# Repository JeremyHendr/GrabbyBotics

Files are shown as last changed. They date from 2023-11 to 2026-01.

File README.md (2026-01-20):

# Grabby – Modular Autonomous Mobile Robot for Warehouse Research  
**Authors:** Jeremy Hendrikse, Julius Ortstadt  

## Introduction
This repository contains all software, hardware designs, and documentation related to **Grabby**, an autonomous mobile robot developed as a **proof of concept for warehouse automation and indoor autonomous navigation research**.

The project has been developed over a three-year period as part of the Master’s program in *Robotics and Autonomous Systems* at **Polytech Nice-Sophia**. The primary objective is not direct industrial deployment, but rather the exploration, integration, and evaluation of autonomous navigation techniques on a self-designed robotic platform.

The system is intentionally modular and extensible, serving as a research and experimentation base for mapping, localization, navigation, and manipulation in structured indoor environments.

> The robot architecture is divided into two main subsystems:
> - **Mobile Base**  
>   Responsible for locomotion, power distribution, onboard computation, and autonomous navigation. It hosts the main computer, battery system, sensors, and motor controllers.
> - **Lifting Platform**  
>   A modular upper subsystem designed for package handling. It includes lifting and grabbing mechanisms as well as additional sensors, such as a stereo camera, to assist with perception and task execution.

---

## Software
This section contains all software developed for the robot, covering low-level control, autonomy, and system integration.

The mobile base software stack is built around **ROS 1 (Melodic)** and includes:
- Teleoperation (wireless controller)
- SLAM and mapping
- Localization (AMCL)
- Autonomous navigation
- Sensor fusion (LiDAR and IMU)
- Motor control and odometry

Due to the use of **Ubuntu 24.04 LTS on ARM64**, ROS 1 is executed inside a **Docker container**, ensuring compatibility and reproducibility despite ROS 1 being end-of-life. Detailed configuration steps are provided in the documentation.

The repository also includes:
- Code for Arduino Nano boards
- Parameter tuning files
- Auxiliary scripts and configuration tools

---

## Hardware
The hardware section contains all design files required to reproduce the robot.

Included are:
- 3D models (Fusion 360)
- 2D designs and schematics (Inkscape)
- Mechanical adapters and modular interfaces

The robot features a **modular chassis built from 20×20 mm aluminum profiles**, carbon-reinforced 3D-printed components, and a decentralized electronics architecture. All subsystems are designed for easy assembly, disassembly, and replacement.

---

## Documentation
This section provides comprehensive documentation covering both hardware and software aspects of the project.

It includes:
- Detailed setup instructions for **Ubuntu Server 24.04 LTS** on Raspberry Pi 5
- ROS 1 Melodic installation and configuration using Docker on ARM64
- Mapping and navigation workspace setup
- Sensor configuration and calibration
- Power system design and safety considerations
- Troubleshooting guides and known limitations

All source code, CAD files, and supporting materials are available in this repository to facilitate reproducibility and further development.

---

## Acknowledgements
The development of this project was made possible through the support of **Polytech Nice-Sophia**, which provided the necessary funding, equipment, and academic framework.  
Special thanks are extended to the professors for their guidance in robotics, electronics, sensor fusion, and autonomous systems, which formed the foundation of this work.

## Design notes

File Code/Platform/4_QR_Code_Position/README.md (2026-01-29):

# QR Code 3D Position Detection using Stereo Vision

This project detects QR codes in a stereo camera setup and calculates their 3D position in space using triangulation.

## Coordinate System and Camera Setup

### Origin and Coordinate Frame

The **origin of the coordinate system is at the LEFT camera's optical center**.

**Coordinate axes:**
- **X-axis**: Points to the right (horizontal, positive = right side)
- **Y-axis**: Points downward (vertical, positive = down)  
- **Z-axis**: Points forward into the scene (depth, positive = away from camera)

```
        Y (down)
        |
        |
        |______ X (right)
       /
      /
     Z (forward)
```

### Stereo Camera Configuration

The stereo setup consists of two cameras arranged horizontally:

- **Left Camera**: Reference camera (origin of coordinate system)
- **Right Camera**: Positioned to the right of the left camera

**Baseline**: The distance between the two camera centers (typically 60-120 mm)

### Extrinsic Parameters

The relationship between the two cameras is described by extrinsic parameters:

#### Rotation Matrix (R)
A 3×3 matrix describing the rotation from the left camera frame to the right camera frame. For a parallel stereo setup (rectified cameras), this is typically close to the identity matrix.

```
R = [[r11  r12  r13]
     [r21  r22  r23]
     [r31  r32  r33]]
```

#### Translation Vector (T)
A 3×1 vector describing the translation from the left camera center to the right camera center.

```
T = [[Tx]    (horizontal displacement - baseline)
     [Ty]    (vertical displacement - ideally 0)
     [Tz]]   (depth displacement - ideally 0)
```

For an ideal horizontal stereo setup:
- `Tx = -baseline` (negative because right camera is to the left's right)
- `Ty ≈ 0` (cameras at same height)
- `Tz ≈ 0` (cameras at same depth)

**Note**: The baseline used in triangulation is `baseline = |Tx|` (absolute value of the x-component of the translation vector).

### Intrinsic Parameters

Each camera has its own intrinsic parameters stored in the camera matrix:

```
K = [[fx   0  cx]
     [ 0  fy  cy]
     [ 0   0   1]]
```

Where:
- `fx, fy`: Focal lengths in pixels (horizontal and vertical)
- `cx, cy`: Principal point (optical center) in pixels

### 3D Position Calculation

The 3D position of a detected QR code is calculated using:

1. **Disparity**: `d = x_left - x_right` (difference in pixel coordinates)
2. **Depth**: `Z = (f × baseline) / d`
3. **X coordinate**: `X = (x_left - cx) × Z / f`
4. **Y coordinate**: `Y = (y_left - cy) × Z / f`

Where:
- `f`: Focal length from camera matrix
- `cx, cy`: Principal point from camera matrix
- `baseline`: Distance between cameras (from translation vector)

### Example Position Output

When a QR code is detected, the output shows:

```
📍 3D POSITION (relative to LEFT camera origin):
   X (right):      45.3 mm    (45.3 mm to the right of center)
   Y (down):      -20.1 mm    (20.1 mm above the center)
   Z (forward):   500.0 mm    (500 mm in front of camera)
   Distance:      502.5 mm    (straight-line distance from origin)
```

### Coordinate System Visualization

```
                    Right Camera
                         ↓
    Left Camera    [baseline]
         ↓              ↓
        [●]------------[●]
         |              
         | Z            
         |↗             
         |              
      Y ↓|              
         |_____ X →     
                        
                [QR Code]
              Position (X,Y,Z)
```

## Files Description

- `3_QR_code_position.py`: Main script for QR code detection and 3D positioning
- `2_get_camera_parameters.py`: Calibration script (in ../Calibration/)
- `retification_informations.npz`: Calibration data containing all parameters

## Calibration Parameters Stored

The calibration file contains:
- `matrix_left`, `matrix_right`: Intrinsic camera matrices (K)
- `translation_vector`: Translation between cameras (contains baseline)
- `rotation_matrix`: Rotation between cameras
- `leftProjection`, `rightProjection`: Projection matrices for rectification
- `leftMapX`, `leftMapY`, `rightMapX`, `rightMapY`: Rectification maps
- `distortion_coef_left`, `distortion_coef_right`: Lens distortion coefficients

## Usage

1. Run calibration (if not done already):
   ```bash
   cd ../Calibration
   python 2_get_camera_parameters.py
   ```

2. Run QR code detection:
   ```bash
   python 3_QR_code_position.py
   ```

3. Controls:
   - Press **'s'** to start/restart QR code detection
   - Press **'e'** to exit

## Display Layout

The window shows:
- **Top**: Live stereo camera feed (left and right views)
- **Bottom**: Last detected QR code with position overlay
- **Top-right overlay**: 3D position information (X, Y, Z, Distance)
- **Bottom bar**: QR code data
- **Labels**: "LEFT" and "RIGHT" on camera views
- **Green boxes**: Detected QR codes

## Requirements

- Python 3.x
- OpenCV (`cv2`)
- NumPy
- pyzbar
- Stereo camera or two synchronized cameras

## References

- Coordinate system follows OpenCV stereo vision conventions
- Origin at left camera is standard in stereo vision
- Extrinsic parameters from `cv2.stereoCalibrate()`
- 3D reconstruction using triangulation from disparity

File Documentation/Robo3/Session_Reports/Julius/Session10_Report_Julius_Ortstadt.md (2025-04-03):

# Session 10 Report - 21.02.2024 - Julius Ortstadt

## Before today's session
- We discussed how we will integrate both parts of the robot together. We came to the conclusion that we will use one big plug for the main data transfert and one smaller for power and ground.
A connector would look like something like this:\
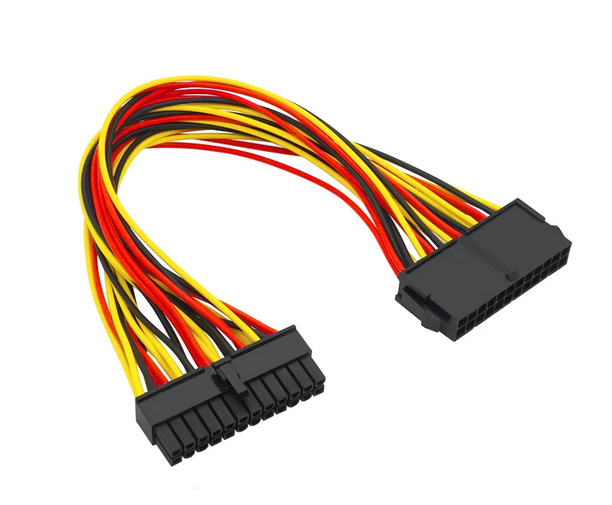
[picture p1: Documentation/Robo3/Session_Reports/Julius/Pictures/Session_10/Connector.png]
Connector


## During today's session
- I repaired some soldered points on the shield. These needed more solder mass and some were not connected, therefore no signal would have been able to pass through.

- I finished soldering the connectors to the Mega shield and started connecting cables to it.\
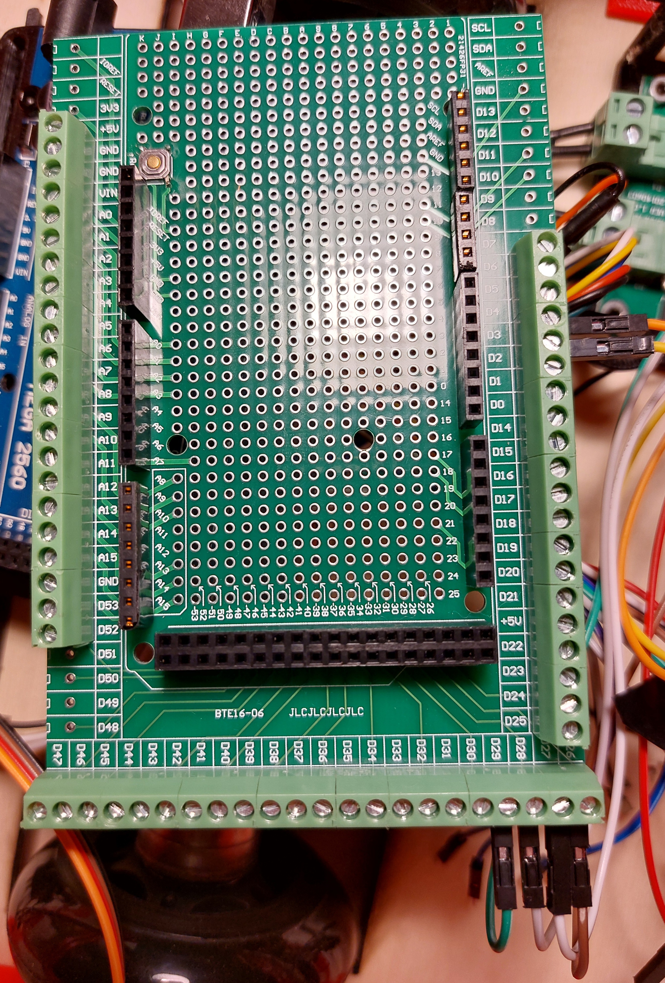
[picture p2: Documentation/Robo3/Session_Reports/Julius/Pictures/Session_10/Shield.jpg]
Mega Shield


- I built a new smaller PCB which will feature all GND and +5V cables from the sensors. Since there are quite a lot, this saves space on the Mega shield and allows for better cable managment in the end.\
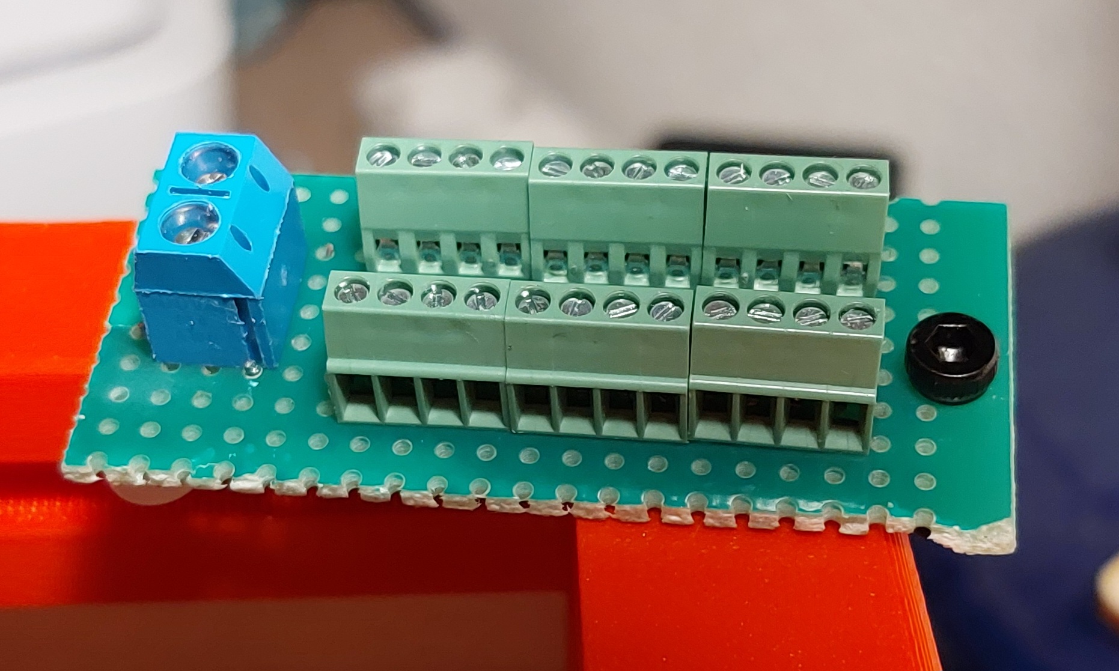
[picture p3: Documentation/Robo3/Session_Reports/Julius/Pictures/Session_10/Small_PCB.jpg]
Small PCB


- I installed the small PCB on the robot. For support I glued some spacers on the bottom side of the PCB and screwed it onto the base plate of the robot.\
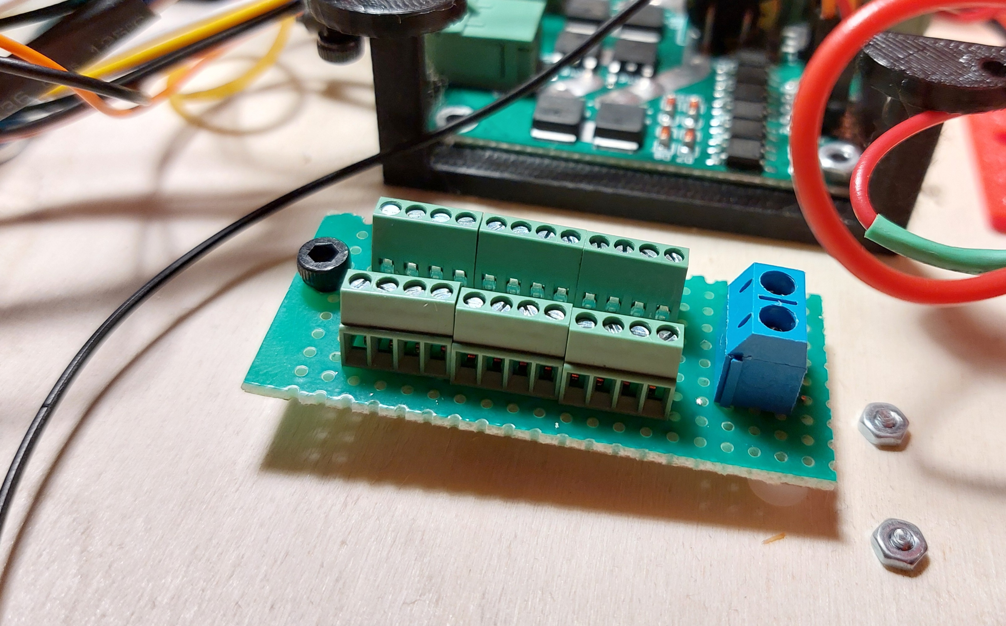
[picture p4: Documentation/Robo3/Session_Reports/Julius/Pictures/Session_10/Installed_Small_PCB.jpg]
Fixed PCB


- I prepared some cables that will be installed later. These will be used for +5V and GND.

- We discussed the possibility of using a QR code scanner on the robot and not necessarily use a camera for that task.

- I made some small corrections to the robot, so that assembly would be easier and re-routed some cables for better cable managment.

## For the next session
- I will continue the assembly of the shield, meaning connect all the cables and sensors. This will allow me to do the first tests of the completed base.

- Code some of the different programms I will need in order to check if everything is working correctly.

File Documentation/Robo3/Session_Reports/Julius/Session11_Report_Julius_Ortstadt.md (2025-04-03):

# Session 11 Report - 05.03.2024 - Julius Ortstadt

## Before today's session
Before today's session I made some modifications to some of the different code snippets.\
Then I also continued the assembly of the shield. 
However I ran into some problems. 
These mainly being faulty solder spots I needed to correct and a missing component. 
This led to me not being able to finish the assembly. 

## During today's session
During today's session:
-  I corrected some errors I made on the Mega Shield. 
I connected some of the solder spots that weren't correctly connected.

- After I made these corrections, I connected the rest of the data cables to the shield.\
Connected Mega Shield

- I also connected all the +5V and GND cables to the mini PCB I made for that purpose. 
As said previously, this allows for more space on the Shield and for better cable managment.\
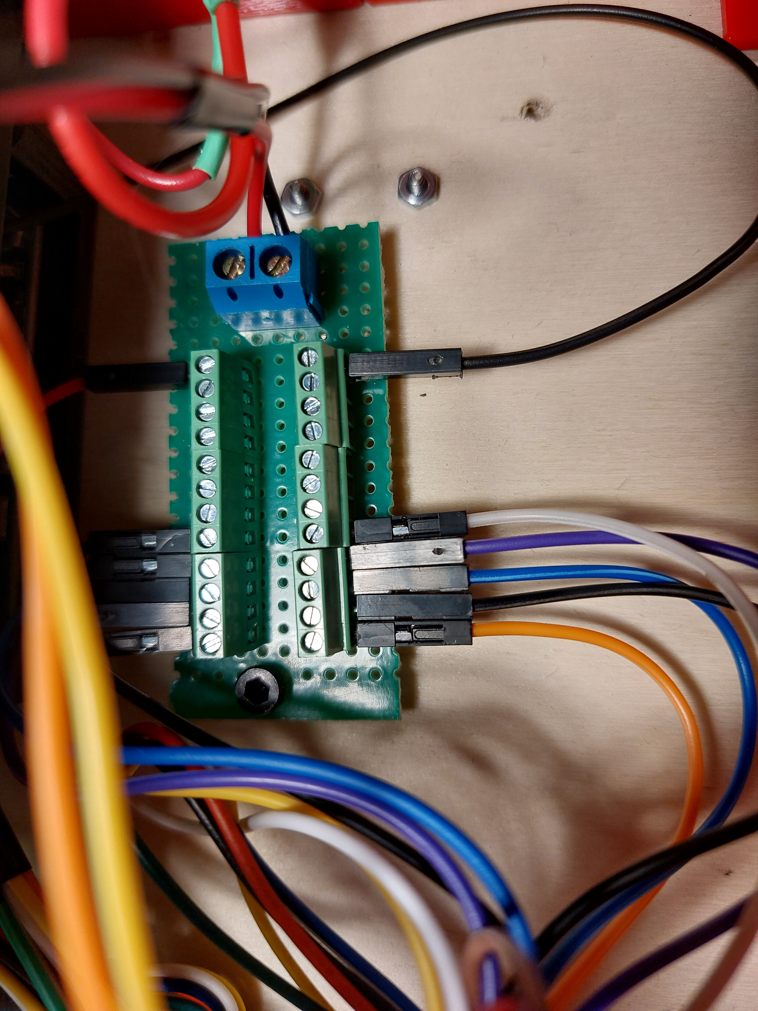
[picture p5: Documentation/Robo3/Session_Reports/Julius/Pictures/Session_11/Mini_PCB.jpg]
Connected mini PCB


This mainly concludes the construction part of the mobil base of the robot. 
There are still some small things that need to be done in order to combine the two parts. 
However, for now, the code is the main point of focus until both parts are ready to be mounted together.\
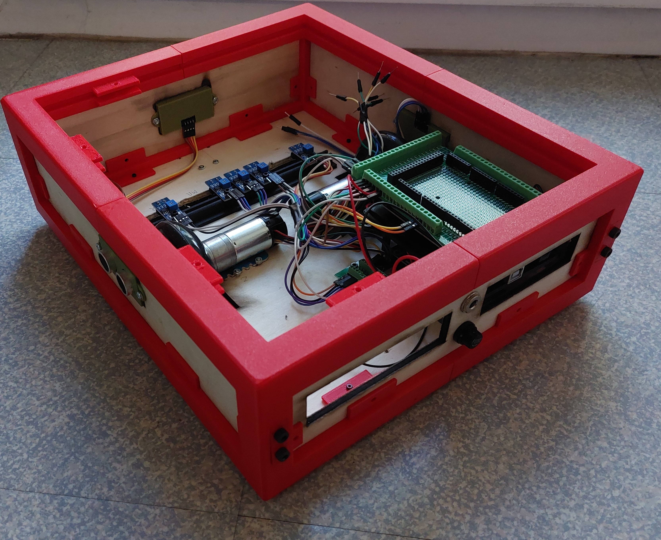
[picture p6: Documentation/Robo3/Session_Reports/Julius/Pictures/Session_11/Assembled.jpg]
Finished construction part of the robot


On the code side of things: 
- After I wired everything up except the Ultrasonic sensors, I had to make some adjustments to some code snippets so that the right pins are read for each sensor.

- I then tested the IR sensors individually to see if they all work properly. 
Additionally, I had to change the detection distance on the sensors so that they see the line correctly.

- I encountered a problem which led to some difficulties with the line following. 
The bottom plate of the robot bent a little bit leading to the fact that the main propulsion wheels didn't have full contact with the ground. 
In order to correct this, I took off the spacer of one of the ball wheels. 
This compensated enough for the bend so that the wheels were touching the ground better.
Later on, we will maybe change from wood to plexi in order to avoid possible bends in the structure and allow for a better overall stability.

- I then re-tested basic motor movements just to see if everything worked well with the new cabling.

- After this was completed, I modified the code I wrote before this session to test some basic line following. 
These modifications included additional variables, the modification of pins, a better code structure and some return values.

- During the test I had a small problem with the center IR sensor which wouldn't detect the line correctly.
I didn't have enough time to correct this today.

## For the next session
For the next session:
- I will need to see why the center IR sensor didn't work properly.
- I will continue the main code.
However, the implementation of the LiDAR at this stage of the project could be benificial.
- I will start working on understanding how to use the LiDAR.

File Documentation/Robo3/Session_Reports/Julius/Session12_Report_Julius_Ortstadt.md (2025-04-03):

# Session 12 Report - 12.03.2024 - Julius Ortstadt

## Before today's session
- As indicated in the previous session report, I started gathering some knowledge about LiDAR technology in general since I've never worked on it before.
- I also tried to find out why the center IR sensor didn't work properly.
However, this wasn't my main point of focus. 
I wanted to get the LiDAR operational as this would greatly simplify the project and reduce the amount of sensors needed.

## During today's session
- Since I already started to learn about LiDAR, I continued my research on this subject but more specifically on the particular LiDAR that I had.
The LDS-02 LiDAR is a spare part for a robot vacuum but can also be used as a standalone 2D LiDAR.

- I tried finding information about this module but this was easier said than done. 
I found some docs about it from a company called ROBOTIS. 
Besides docs for the LiDAR they also had a GitHub repo in which was a driver for the module.
However understanding how to connect the module to the Arduino or even the PC was the main problem.

- In order to connect the LiDAR, I had to remove the pre-mounted connector since I didn't have the male-cable for it. 
I then soldered some cables to it with a connector at the end for which I had a fitting cable.\
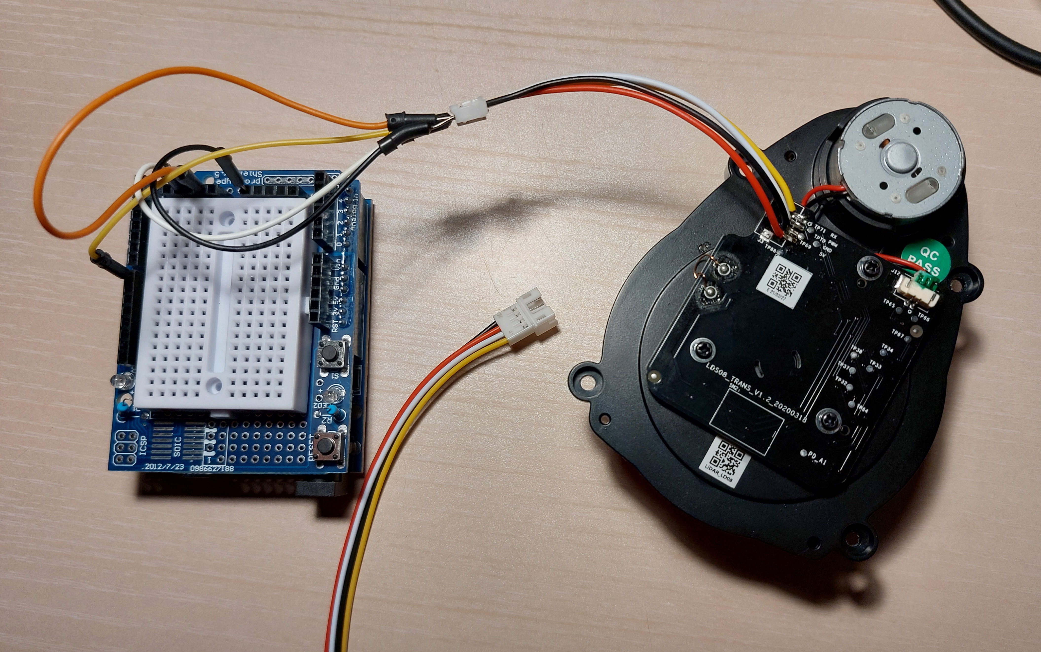
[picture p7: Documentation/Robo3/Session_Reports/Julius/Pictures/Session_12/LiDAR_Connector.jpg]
New connector


- The next step was about finding out how to receive data from the module. 
The problem was that the LiDAR doc had 4-pins: +5V, GND, TX, RX. 
However, the module that we had, had: +5V, GND, RX, PWM.
So we needed to find out how to communicate with the module.

- After continuing my research about this LiDAR I found out that the ROBOTIS team, in order to use the module with an Arduino, used a board manager in the Arduino IDE called OpenCR.
In order to install this board, I first had to find an ...index.json URL for this board since as a third-party board it isn't pre-loaded in the IDE.
After a lot of search I finally found what I was looking for and after some more research into how to actually load it into the IDE, I did just that.
Now I could use an example code provided with the OpenCR board.
The problem was just that the code was for displaying the data on a LCD screen shield for the Arduino.
I will need to figure out the code to modify it so that I can maybe display it in the IDE or another way.

- There still was the problem with figuring out the driver. 
There was no information about how to use it with the LiDAR.
We tried to understand the code but we still have some difficulties especially since the ports on the LiDAR don't correspond with the ones in the doc.
We will try to see how the LiDAR communicates via an oscilloscope.
If this doesn't work out we will maybe have to order another LiDAR built to be used with Arduino and/or Nvidia Jetson.
But we are not giving up yet.

## For the next session
- I will connect the RX port of the LiDAR to an oscilloscope in order to see what type of signal is sent by the module.

- I will continue to try to read data from the LiDAR and try to understand how it communicates.

- I will try to figure out how to use the driver provided by ROBOTIS.

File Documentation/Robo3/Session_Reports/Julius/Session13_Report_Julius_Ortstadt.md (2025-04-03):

# Session 13 Report - 19.03.2024 - Julius Ortstadt

## Before today's session
- After connecting the RX on the LiDAR to an oscilloscope, I saw that it was indeed sending data through this port which seems counterintuitive since it is called RX.

- The first thing I tried to do was to read data from this module.
The idea was to read a data packet sent by the LiDAR with the help of the Arduino UNO. 
I knew that there would be a bottleneck by simply comparing the amount of data sent by the LiDAR and the speed of the Arduino.
As I said, I only wanted to read some data, decrypt it and have a comprehensive piece of information where I could find the distance and the angle of a point.
After a lot of research on Arduino Libraries I found one that specialized in reading data packets send to a serial port of the board.
For that, I needed to define a new serial port on the Arduino using the SoftwareSerial library. 
This essentially allows the creation a new serial communication port besides the standard D0 & D1 for RX & TX on the Uno which only has the one.
In the end, I indeed received some data from the LiDAR as a packet, however it was incomprehensible. 
The encoder from the PacketSerial library was not made for this type of data transmission which ultimately lead to it not displaying the data correctly.

- I also tried using the driver which I found but I wasn't very successful with this either.

After all these tests I concluded that I order to use this LiDAR I would need way more time to make it work properly and even then I wouldn't have a guarantee that it would work.
I therefore decided to use another LiDAR that was in storage but more on that in the next session of this report.
 
## During today's session
- After we made new plans about how we will merge the two parts of the robot, a few adjustments to the frame were needed. 
The main change was to ease installation. 
I replaced the previous holding mechanism for the wood panels. 
It was replaced by a system that would essentially just screw the panel onto the frame and therefore hold everything together.
This change reduced complexity in both assembly and printing since it would need less supports.
We then started to think about the connection between the two parts.
We will integrate a spacer system on top of the frame instead of just a normal spacer in order to minimize stress on the insert. 
The M5 insert will then be put on the top of the spacer where the other part will be mated to.
The last addition is not yet visible on the render:\
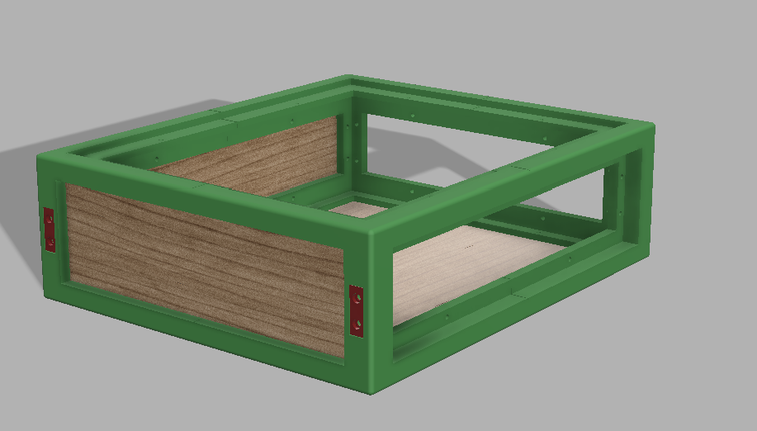
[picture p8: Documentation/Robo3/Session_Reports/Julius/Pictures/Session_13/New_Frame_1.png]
New frame assembly 1
\
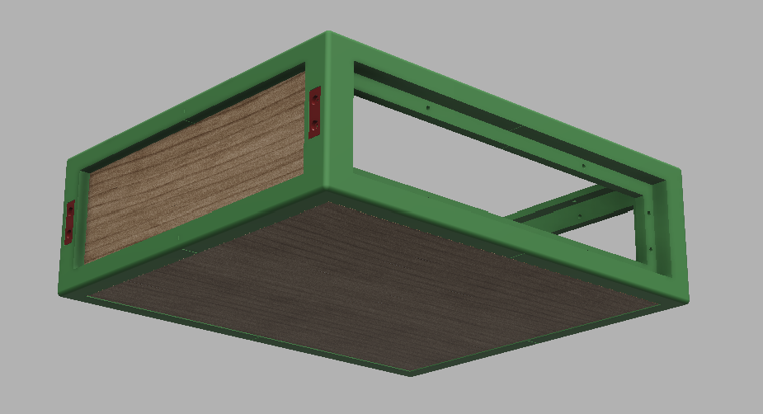
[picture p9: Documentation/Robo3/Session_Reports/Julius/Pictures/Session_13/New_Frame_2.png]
New frame assembly 2
\
The reason why we need the spacers is that there will be the LiDAR between the two parts.
This will enable us to get a 2D map of the area from not to high above, about the height of a normal vacuum robot.

- I the started to use the new LiDAR A1 from Slamtec.
I connected all the necessary cables.
After reading the documentation, I installed the software provided by the manufacturer: Slamtec RoboStudio. 
The software allows the user to visualize all the data and even use SLAM algorithms and more.
However, before this could work on Windows 11, the driver for the signal converter board needed to be installed. 
Since the LiDAR sends data via UART, a UART to USB module was provided, but so that Windows could detect this module, a driver was needed to be installed. 
After everything was installed, everything worked properly and I could visualize the data.\
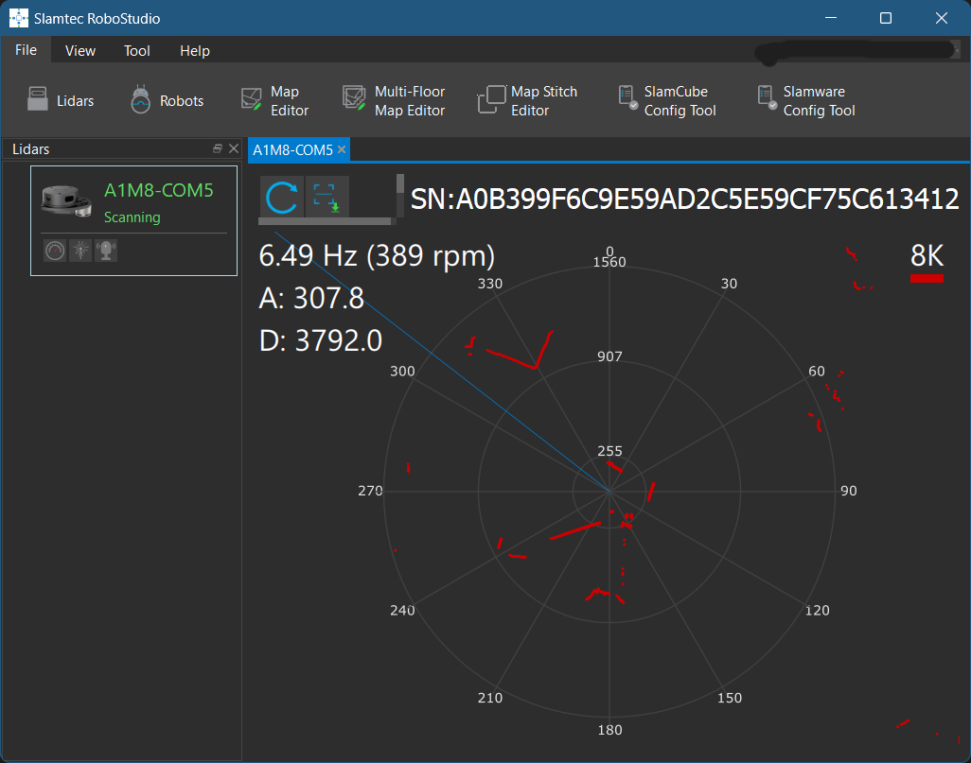
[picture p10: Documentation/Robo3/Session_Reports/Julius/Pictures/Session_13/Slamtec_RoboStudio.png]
Data from the LiDAR


## For the next session
- I will continue my work with the LiDAR and try to use it with the NVIDIA Jetson since in order for the robot to work, the LiDAR will send data to the Jetson, which will process it and take a decision and send it to the Arduino which will eventually move the robot where it needs to be.

- I will continue the redesign of some of the pieces of the robot in order to accommodate the changes that will need to be done.

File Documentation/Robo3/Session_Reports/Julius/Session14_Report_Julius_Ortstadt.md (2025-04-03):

# Session 14 Report - 29.03.2024 - Julius Ortstadt

## Before today's session
We had the chance to have our computer science class before this project session. 
During this class, we learned how to connect the Arduino and the NVIDIA Jetson Nano. 
This helped a lot with the overall progress of the project.

- First, I did my research into how the Jetson would work with the LiDAR, how it will analyze the data etc..
I found out that this would best work with ROS.
I then set out to start learning about ROS overall and how to use it, what it does etc...
I found some tutorials online and started working on the installation process and all the rest.

- However, before I installed ROS I had to add another feature to the Jetson. 
My goal was to use the Jetson as a headless device, meaning I would have the desktop as a remote desktop on my notebook, I could also use it with the keyboard and mouse from my notebook. 
In order to achieve this I had to install NoMachine on both my computer and the Jetson and then setup different things so that everything could work over Wi-Fi.\
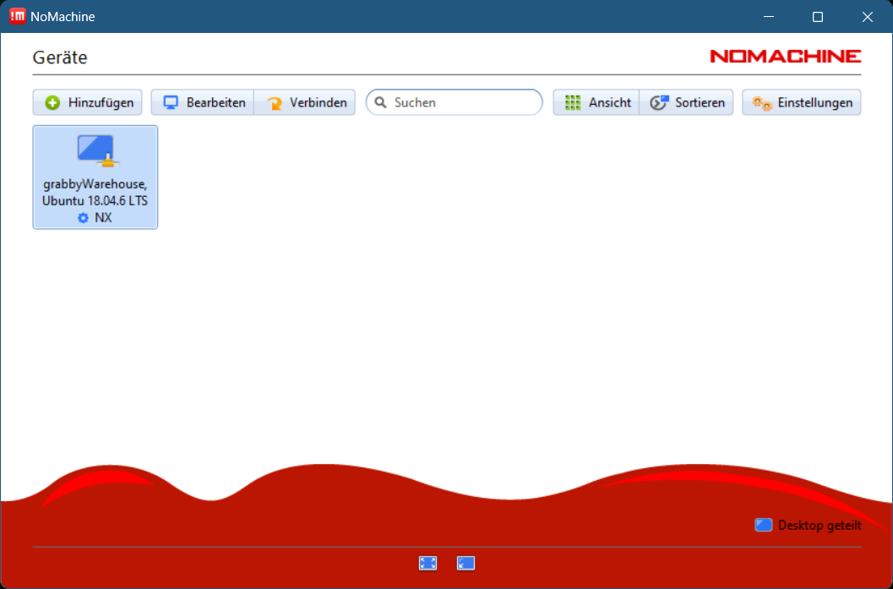
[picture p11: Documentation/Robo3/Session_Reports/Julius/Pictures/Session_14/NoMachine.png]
NoMachine on Windows detectin the NVIDIA Jetson Nano
\
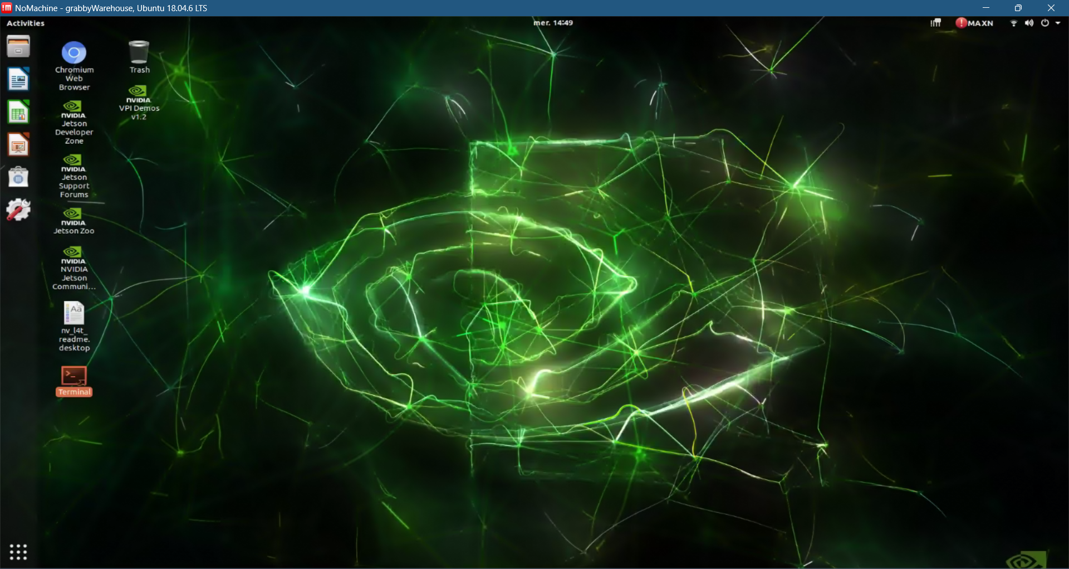
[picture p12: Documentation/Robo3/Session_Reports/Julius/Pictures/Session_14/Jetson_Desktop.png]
Jetson Desktop
\
I also installed JTOP on the Jetson so that I could monitor the performance, memory usage, CPU & GPU load etc.\
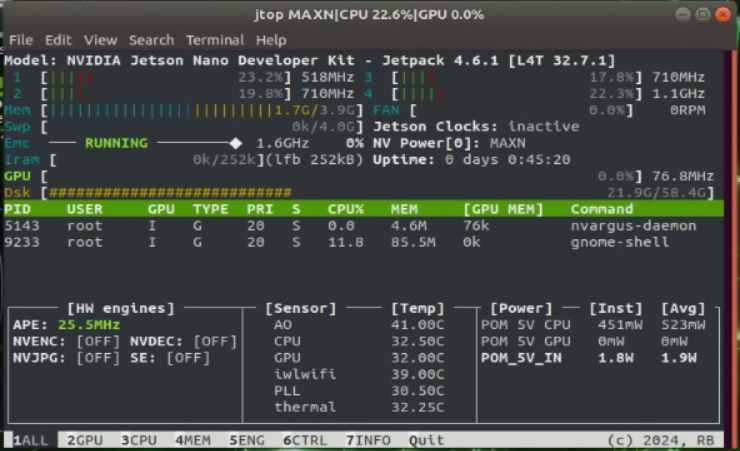
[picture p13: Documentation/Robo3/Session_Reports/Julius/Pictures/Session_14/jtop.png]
JTOP


- I then installed ROS onto the Jetson so that I could work on the LiDAR. 
For this project, I decided to use ROS Melodic since it is very well documented and there are existing projects that use Melodic with the Slamtec A1M8 LiDAR that I have. 
The possibility of using examples was one of the key points to choosing this distribution since I don't really know how to use ROS very well and this would help me use and understand it. 
The installation process was pretty long because I installed the full version of this distribution so thaht I could have access to all the tools I would need.
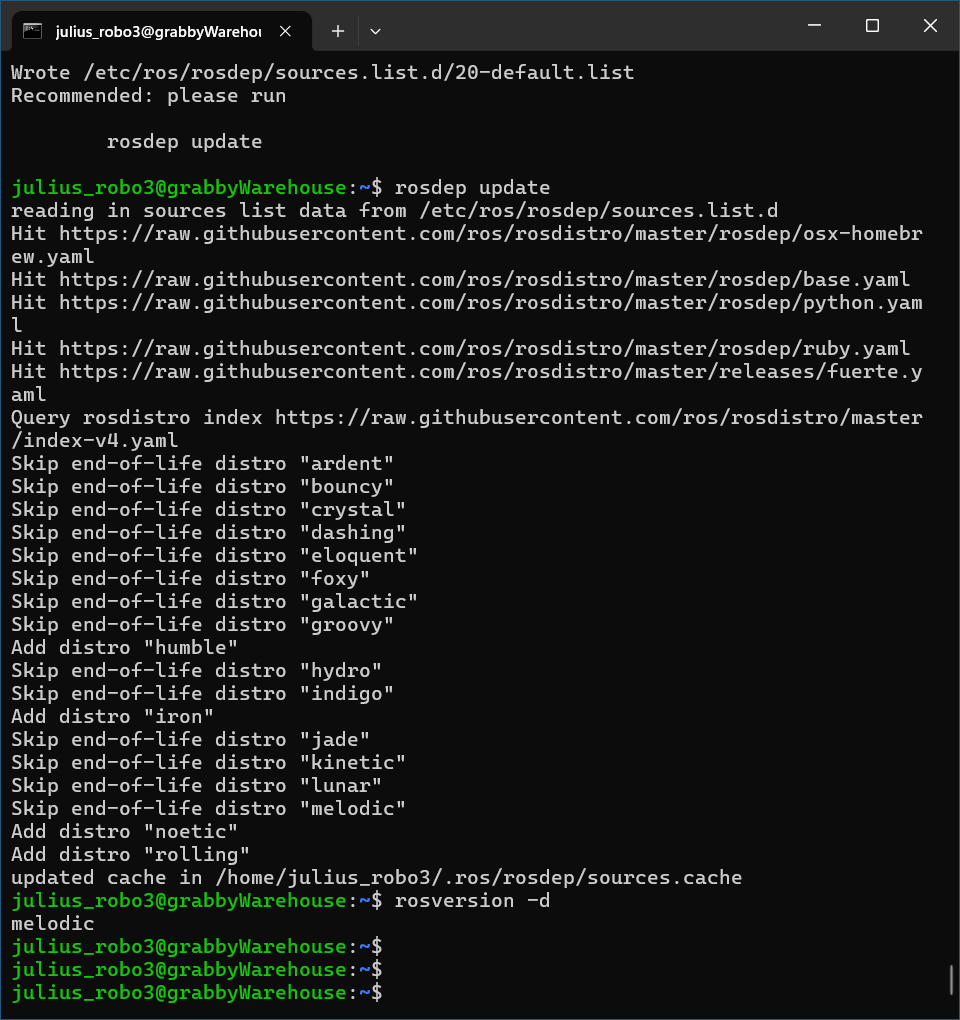
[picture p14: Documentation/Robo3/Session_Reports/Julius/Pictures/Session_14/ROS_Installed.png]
ROS Installed


- In parallel to all this I also started writing a documentation of all the steps I undertook for NoMachine and ROS to work properly so that later on others as well as I can come back to the project and understand how everything was done.

- I continued my research on mapping a room with a LiDAR using Hector-SLAM. 
Achieving this is the next goal for this project.

- I made some changes to the frame that I didn't get to do last time. 

## During today's session
The base for today's session was laid thanks to the work done before this class.

- I tested the angular drift of the LiDAR, in other words, I tested what the angle of the laser was relative to a horizontal plane. 
This was necessary so that I could see how deep I could lower the LiDAR into a plane.
I had the value given by the manufacturer but I wanted to check so that there would be no unexpected surprise.
Manufacturer data

- I designed a holding system for the LiDAR to put in between the two parts of the robot without taking up to much space.
The piece needed to fit the LiDAR itself, the UART to USB converter and the cables.
The whole piece will rest on the overlap that will be screwed onto the top plate of the frame.\
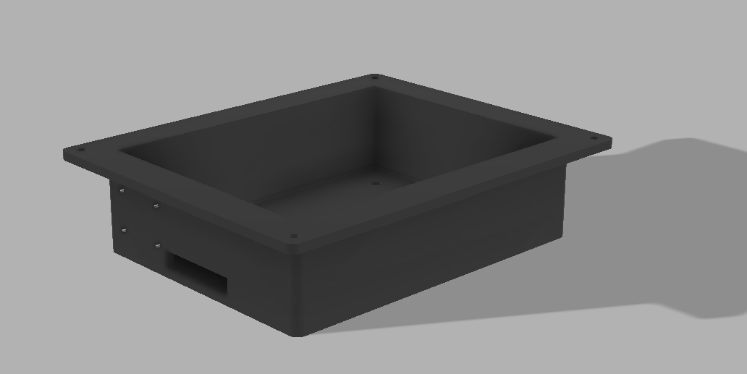
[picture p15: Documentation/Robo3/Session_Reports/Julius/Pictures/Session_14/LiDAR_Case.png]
LiDAR box


- I continued working on the frame. 
I corrected some small mistaked that I overlooked last time.
Additionaly I started working on the pilars that will hold together both parts of the project.\
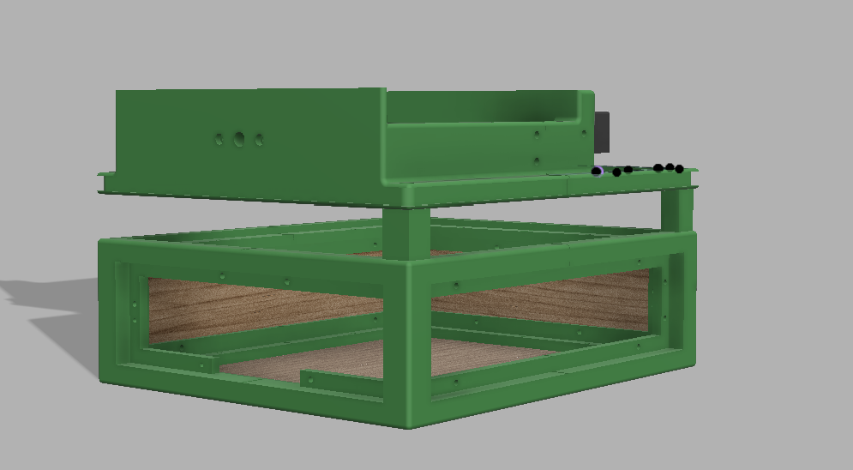
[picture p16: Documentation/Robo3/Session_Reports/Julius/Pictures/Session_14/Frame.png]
New started frame
\
As I already said, the frame is not finished yet.

## For the next session
- During the next session we will hold a presentation about the progress since the last time we made an update. 
This will allow us to show what has been done, what we changed, why and what still needs to be done.

- I will try to interface the LiDAR with the Jetson and to get the data from the module and display them.

- I will try to make the robot map a room using the LiDAR and a basic object avoidance system with the Arduino and a proximity sensor (ultrasonic sensor) so that the robot could move around the room.

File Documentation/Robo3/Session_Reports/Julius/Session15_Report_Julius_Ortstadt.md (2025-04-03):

# Session 15 Report - 02.04.2024 - Julius Ortstadt

## Before today's session
- I was working a lot on the LiDAR and the Jetson. 
This is why I created a documentation of all the steps I undertake as I progress throughout the project. 
I continued to write this documentation. 

- For the LiDAR to work I had to modify the ROS launch file provided with the LiDAR package.
Then you have to launch both roscore so that you have a master to manage all the topics, and the launch file itself in order to publish data to the other nodes.\
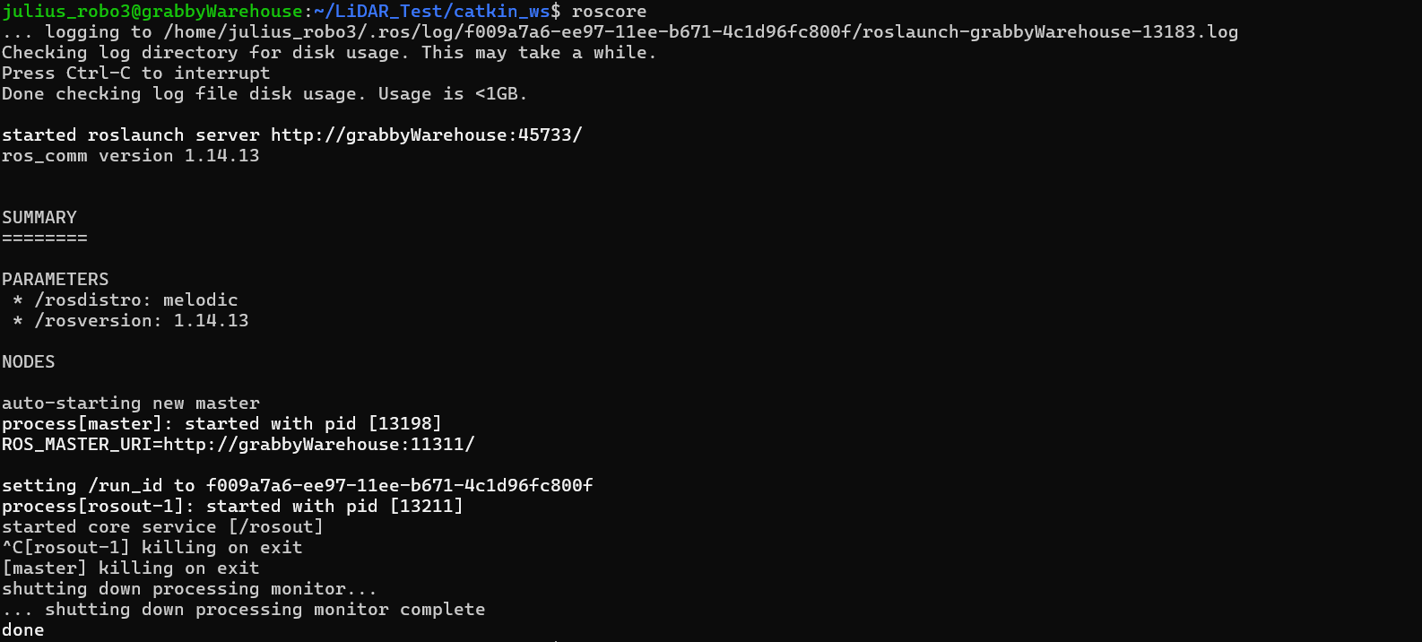
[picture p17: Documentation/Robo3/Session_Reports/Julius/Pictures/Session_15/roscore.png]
Roscore
\
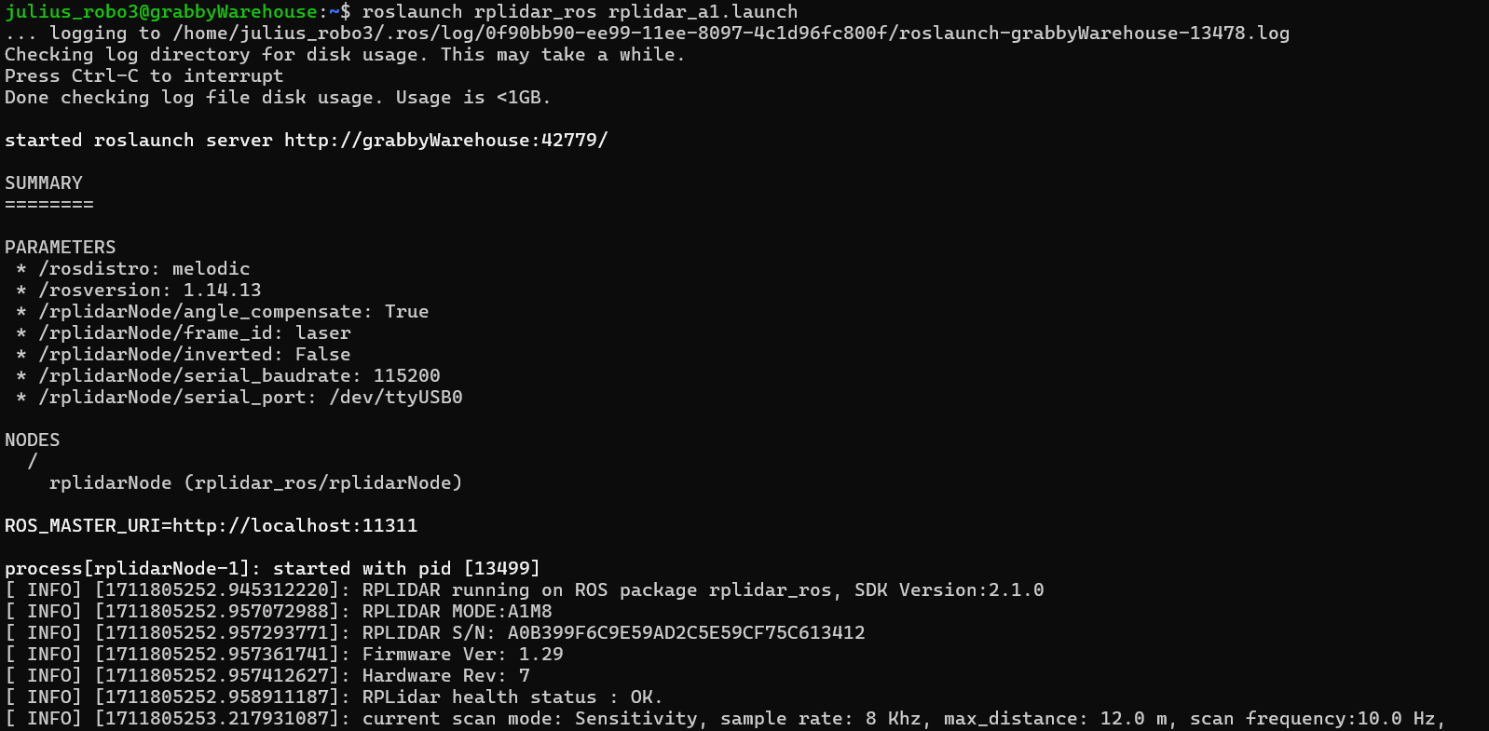
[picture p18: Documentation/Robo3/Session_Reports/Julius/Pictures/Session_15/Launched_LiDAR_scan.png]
Roslaunch


- I then had my first success with the LiDAR.
I could now visualize the data in the terminal (the raw data)\
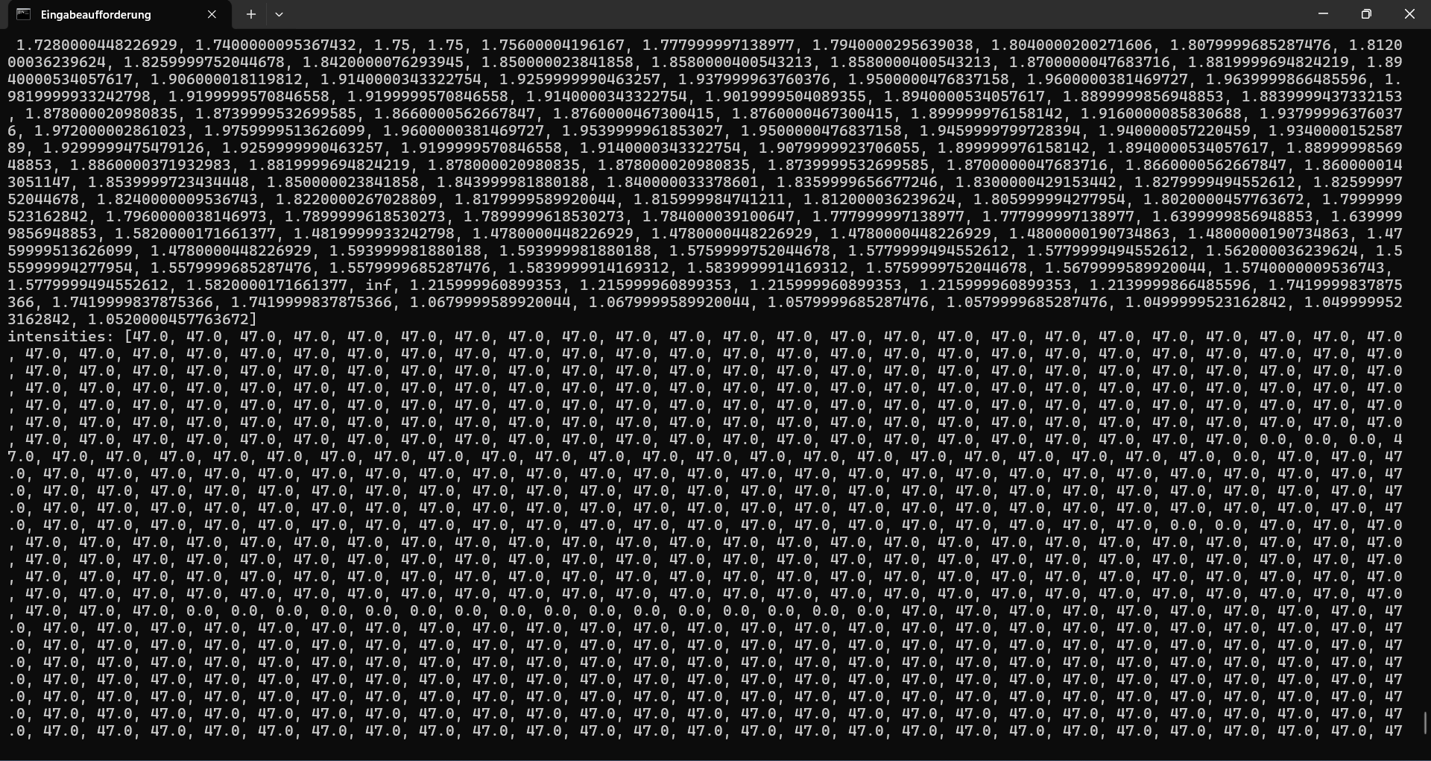
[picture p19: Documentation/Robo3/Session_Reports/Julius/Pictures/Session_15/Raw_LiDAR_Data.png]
Raw LiDAR Data
\
and later in rviz.\
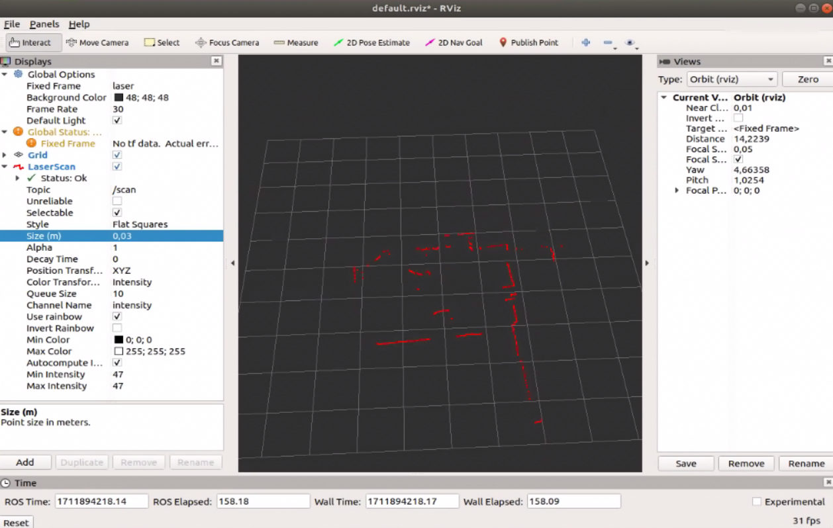
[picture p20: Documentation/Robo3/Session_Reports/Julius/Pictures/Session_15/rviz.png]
Rviz visual

Rviz is a visualization software included in the ROS package which I used for the LiDAR.
Here is a live view:

https://github.com/JeremyHendr/GrabbyBotics/assets/120115242/fcc1d2d0-ea8c-4255-8718-83cb4c6e21bf

- Since the LiDAR was now correctly working with ROS, I had to setup the Hector SLAM. 
Hector (Heterogeneous Cooperating Team of Robots) SLAM is a SLAM algorithm that allows the robot to know where it is in a room without odometry data.
Meaning it knows where it is solely thanks to certain points in the LiDAR data.

- Now that Hector SLAM was installed, I needed a robot that can navigate a room without bumping into everything so that I could map the room.
I first tried to create a basic bluetooth remote with my phone and a HCSO6 bluetooth module. 
However the module wasn't working properly which led me to abandon this idea.
I instead coded a basic obstacle avoidance programm utilizing the from sonar and the Arduino.
I then performed some basic tests.

- Now that everything was ready I needed to integrate the Jetson and LiDAR with Grabby itself.
I had to improvise a little bit. 
Here is the test setup:\
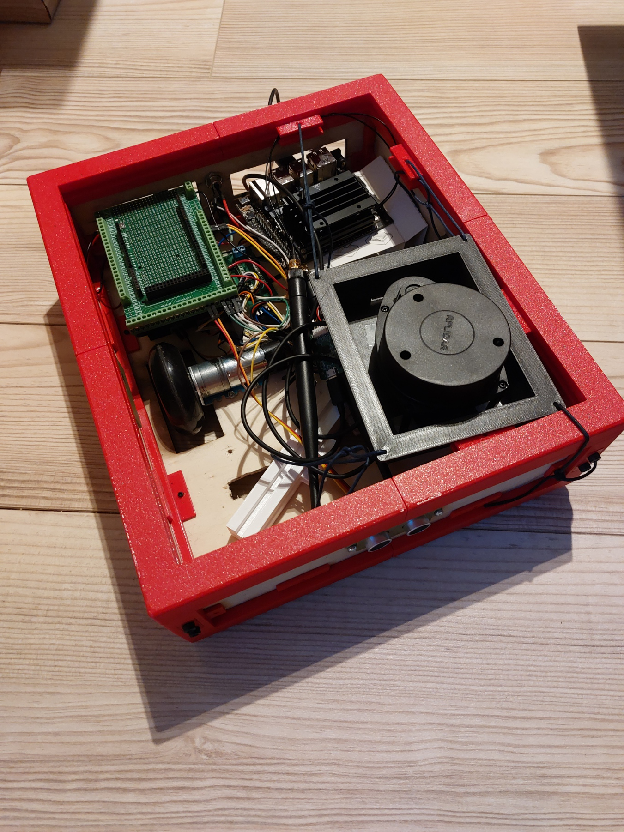
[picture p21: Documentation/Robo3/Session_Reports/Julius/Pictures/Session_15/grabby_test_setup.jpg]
Test setup
  

- Everything was ready for the first mapping test. 
Here are two videos, one view is from rviz showing the realtime creation of the map and the other shows the robot navigating so that the map can be created. 
Note that the videos are sped up.

https://github.com/JeremyHendr/GrabbyBotics/assets/120115242/86aef2d8-5312-4246-a183-24707fe7e197

https://github.com/JeremyHendr/GrabbyBotics/assets/120115242/7278811c-f9ad-4bdc-be21-e6ae00db4dca

- You can see in the two videos, that the robot moves in the map. 
However the quality of the map is poor because the robot was moving to fast.
The speed of the robot is what needs fixing. 
However, this is the lowest I can set the motors so that they start. 
I will need to do some research into how to fix this. 
This is really important to get a high quality map.

- I also made some small design changes to the LiDAR case. 
I juste needed to move a few holes for the UART converter.\
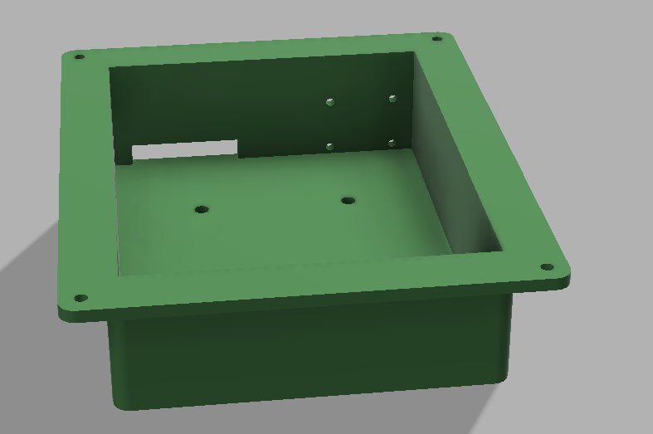
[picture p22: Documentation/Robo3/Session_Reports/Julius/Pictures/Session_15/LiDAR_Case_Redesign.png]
LiDAR case


## During today's session
- We had our progress presentation.
We presented everything that has been done since the last time. 
This included for the mobile base:
    - The frame
    - The LiDAR work
    - The Arduino Mega shield
    - The work with the Jetson
    - and much more

- I also started the real final version of the frame. 
It will take a total of two printing sessions for the entire frame to be finished.

- During my previous work I came to the conclusion that my Arduino / H-Bridge stack was too much of a hassle to work with. 
We came up with the idea of simply putting the H-Bridge vertical onto one of the side panels and just use spacer for the Arduino.

- Setting up the Jetson as headless, starting all the scripts and everything is a lot of work everytime the Jetson is turned on.
Therefore, I started to code a simple start-up script, which would execute everytime the Jetson starts.
This script configures the board for headless mode, sets the execution rights for the USB, launches roscore and the necessary launch files.

- I continued working with Hector SLAM trying to correct some errors in the map creation but I couldn't get it to work properly today.

- I continued my work on the documentation.

## For the next session
- I will finish printing the frame.
However for this frame to be assembled I will wait to have the base plate (made from plexi) ready, so that this would be the final assembly.

- If I have some time, I will start designing the plexi parts of the robot but this is not a priority yet.

- I will continue working on the virtual (Fusion 360) robot prototype so that all the holes I will need can me made with the laser cutter.

- I will continue writing my start-up script.

- I will also continue my work with Hector Slam.

- I will also look into how I can reduce the motor speed for better mapping performance.

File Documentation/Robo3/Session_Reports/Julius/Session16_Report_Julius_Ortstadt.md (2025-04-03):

# Session 16 Report - 09.04.2024 - Julius Ortstadt

## Before today's session
- I finished printing the new frame.
The only thing left to do now is to place the inserts and assemble it.

- After some research into how we can reduce the motor speed for mapping etc. , we came to the conclusion that it would be better to order other motors with a higher reduction ratio.
This would allow the motor to drive at lower speeds.

- I continued my work on the Jetson by installing the Arduino IDE on it and performing some basic tests to check the connection (via USB) between the two.\
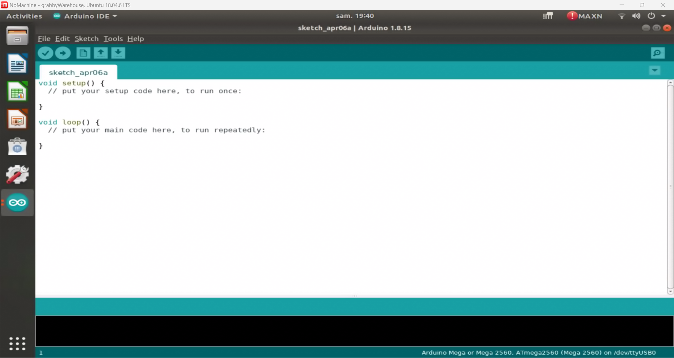
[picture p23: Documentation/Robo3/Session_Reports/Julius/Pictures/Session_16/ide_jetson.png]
IDE on the Jetson


- I tested the connection by using a little script allowing me to make the built-in LED on the Arduino blink.

- I wrote a script that counts the pulses send by the motor encoder. 
This will later be usefull to determine the speed of the robot and its position.\
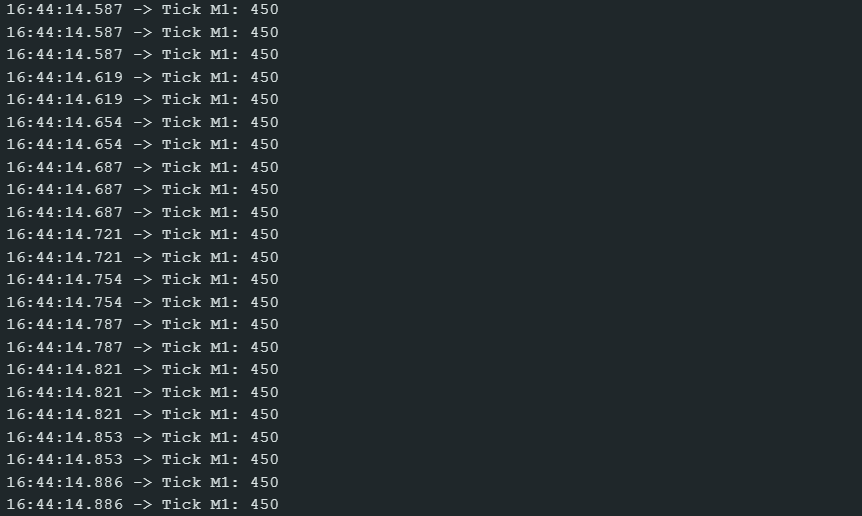
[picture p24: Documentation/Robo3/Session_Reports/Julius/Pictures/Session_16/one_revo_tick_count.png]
Ticks


- After testing this script, I had some problems with one of the encoders which didn't seem to work.
I will have to get back to that issue later.

- I then started catkin workspace for the robot in which we'll put all our code relative to ROS.

- I tested the publising manually:\
Manually Published data

- I started writing the launch file for this project which initially allowed the Arduino to publish, on a ROS topic, the encoder ticks from the motors.\
Publishing via the launch file

- I then added the LiDAR compatibility to the project which I setup during the last sessions.

- I added the LiDAR to the launch file which worked fine.
However I will need to figure out which USB port is given to which module so that they have the right references in the launch file when multiple devices are connected via USB.

- I wrote a script for the Arduino which will allow me to control it through the jetson via a GUI provided by ROS.
The script included publishing Twist messages (messages containing linear and angular velocity data), calculating the resulting PWM for the motors, applying the calculated PWM, determining the wheel velocity, correcting the velocity of each wheel so that the trajectory is what is asked...

- After all this I also continued my work on the documentation which retraces all the steps I made to setup the Jetson for this project.

## During today's session
- We made some fast calculations of our power consumption on the entire project. 
This enabled us to get a rough size for the battery.
We will probably need a battery with a capacity of a little more than 5000mAh, a voltage of 14.4V and a good enough discharge rate.

- Since our battery will give out 14.4V, we will need a DC-DC converter. 
We determined the specs of the converter we needed and started testing it.
We chose a Buck-Boost converter.

- Also, since we will have the Jetson running SLAM and a QR code recognition via vision, it will probably heat up a lot.
For that matter, we decided to add fans to the robot.
One on the top part to cool the H-Bridge.
And two in the mobile base: 
    - One for the Jetson directly on the heatsink.
    - One below the top panel, blowing air through the entire base.

- I designed an adapter for the H-Bridge so that it could fit onto the side panel.\
Adapter

- I started incorporating those different design changes in the 3D model of the robot.
This simultaneously allowed me to place the holes etc. for the panels so that the creation of the DXF files for the laser cutter will be easier.\
New robot design

## For the next session
- I will continue and maybe finish the 3D design of the robot.

- I will start printing the new pieces I need.

- I will continue my code for the navigation.

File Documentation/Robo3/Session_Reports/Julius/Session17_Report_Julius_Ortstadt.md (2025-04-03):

# Session 17 Report - 16.04.2024 - Julius Ortstadt

## Before today's session
I did multiple things before today's session:
- I continued working with ROS. 
I haven't made a lot of progress, I mostly read articles about how to do different things.

- I made 3D versions of some parts for the robot. 
This allows me to create a complete 3D model of the robot before completely assembling it.\
Arduino Assembly\
Jetson Assembly
- I continued the overall 3D design of the robot so that I could print and cut the new pieces during the session.
This included adding all the other components to the 3D model.\
3D model

- I made some new charts and docs for the project. This allows us to keep everything organized and so we know what still needs to be done etc.

## During today's session
- After talking about the battery, we decided to get a new power supply first and the battery when everything works properly. 

- We received our screw order.
This will allow us to proceed with a clean assembly of the robot.

- I printed the revised versions of some components.
I can now proceed with the installation of some of them because the print failed at some point, leaving some components unfinished. 
I will need to print those again.\
Newly printed components

- I finished the 3D model of the bottom plate of the robot where most of the components will be fixed to.\
Bottom plate

- I cut the wood panels for the bottom of the frame as well as for the sides and the front.
I need more time to finish the back panel. 
I will therefore cut the back and the top one later.

- I put inserts into the front of the frame.
This will allow us to remove the front panel by just removing the screws whereas the side panels are hold in place with screws and nuts which makes disassembly much more complicated.
We did this to allow access to the robot.

- I started the assembly of the new frame.
We can already see that it will be much more robust when compared to the old one.\
New frame assembly

## For the next session
For the next session I will:
- Continue the model of the robot.

- Add the remaining components to the 3D robot.

- Continue my work with ROS.

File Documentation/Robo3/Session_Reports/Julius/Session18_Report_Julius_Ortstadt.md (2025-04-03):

# Session 18 Report - 07.05.2024 - Julius Ortstadt

## Before today's session
- I continued the 3D model of the robot so that we have a complete virtual view of it.
- For this model to be complete I needed to create a few other models of some components. 
In this case of the switch which we'll use.\
Switch 3D model
- Now that I had everything for the virtual assembly, I integrated the components and finished the back panel design.\
Back panel
- Online I found a 3D model of the exact shield for the Arduino Mega that I was using, this allowed me to add it to the 3D model. 
This enabled me to see how everything would fit inside the robot.
- I had a problem during the last session where the encoder for one motor. 
After a few tests the problem was solved. 
The issue was a faulty cable.
- I made some progress on the assembly of new robot, which will be the final version.
- After this part of the assembly, another problem occured. 
The motors didn't work. 
The problem was another faulty wire responsible for the power supply. 
After replacement the motors worked properly.
- I then did a motor check through the Arduino connected to the Jetson nano via USB.
- I continued my code which would allow me to send velocity commands to the Arduino with the help of ROS.
I needed to troubleshoot a lot of things for this to work since some of the connection didn't work properly and there were also some other problems related to the encoders, the interrupts, the usb connection etc.
I managed to solve all of these problems and I started integrating this programm into the launch file I created for this project.
- I put the inserts for fixation of different parts into the robot. 
These were for the top panel, the back panel, the left side panel and the merge points for when we connect both parts of the project.
- I started a new print for the components that weren't printed correctly last time.
- I also designed and printed some custom spacers for the jetson nano.\
Custom spacers
- I made some changes to the top panel to help with cable managment.
- I cut the back panel and the top panel so that I could start assembly.
- I installed the fan on the top panel.

## During today's session
- I swapped the old motors for the new ones.
These will allow the robot to move slower while increasing torque in order to create a good map of the warehouse and to increase precision.
- I made some small corrections to the back panel as some of the holes were too small.\
Back panel fixed
- I fixed the Jetson nano to the robot. 
I couldn't do this earlier because I didn't have the right spacers (I needed to print them).\
Installed Jetson nano
- I gathered some components for the final steps of assembly.
- I re-routed some of the cables for better cable managment.
- I added the LiDAR case to the top panel.\3
Installed top panel
- I worked on the power connections for the project.
I did a quick sketch and will later start soldering everything together.

## For the next session
- I will finish the assembly of the robot.
- I will continue to work on the software for the navigation.
- I will add some final touches to the mobile base.

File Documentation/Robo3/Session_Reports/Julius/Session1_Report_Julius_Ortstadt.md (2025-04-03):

# Session 1 Report - 14.11.2023 - Julius Ortstadt

During today's session, I gathered components for the robot and started testing and modelling them.
These included:
- 3 different types of IR Sensors for the line following.
- 1 ultrasonic sensor
- 1 set of screws

I also made some sketches and wrote down some ideas. These included sketches of how the robot will implement the motors, wheels and how to manage the space. Since there isn't much of the latter, it is important that we optimize space between the motors, the sensors, Arduino, Jetson and maybe a battery.\
Sketch 1

Another sketch also visualized the 1st base prototype to test the motors and the line following.
Sketch 2

Other elements done during this session included:

- Test of different IR-sensors (single sensor and board with 5 sensors) via Arduino in order to test their functionality and to see if the black tape is working with these sensors. Module chosen for the robot: TDRCT-5000
```
/*
 * Code to test IR board with 5 sensors
 */

const int IR1 = 3;

void setup() {
  Serial.begin(9600);
  pinMode(IR1, INPUT);
}

void loop() {
  int IR_Stat = digitalRead(IR1);
  if (IR_Stat == HIGH){
    Serial.println("HIGH");
  }
  if (IR_Stat == LOW){
    Serial.println("LOW");
  }
}
```

- 3D model creation of Infra_Red Sensor board TDRCT-5000.\
TDRCT-5000

- 3D model creation of Motor 4844.\
Motor-4844

- 3D model creation of motor holding bracket.\
Bracket

- Start of 3D model creation of holding system for HC-SR04 ultrasonic sensor.

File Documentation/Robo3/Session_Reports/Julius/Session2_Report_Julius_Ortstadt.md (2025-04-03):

# Session 2 Report - 21.11.2023 - Julius Ortstadt

Before today's session I received the last components from the 1st order that I needed in order to start building the prototype. Those components being:
- 2 motors with gear reductor and encoder
- 1 control module to control the two motors
- 2 scooter wheels that will be motorized
- 2 wheel hubs in order to fix the wheels on the motor shaft
- 2 ball caster wheels that will assist with stability
- 2 support brackets to hold the motors in place

I also started creating 3D models of some of these components where I had a datasheet with the precise measurments.
I created models for:
- the scooter wheel. We chose this type of wheel since it offers a good amount of grip on the surface the robot will navigate on. Additionally it doesn't take up a lot of space which is benificial since we don't have a lot of it.\
Scooter Wheel

- the wheel hub that will connect the wheel to the motor shaft. It will clam the wheel from both sides. Then two little screws allow the entire structure to be fixed the the shaft.\
Wheel Hub

During today's session, I continued the 3D models of different components so that an assembly of the entire robot could be made within Fusion 360.
I continued with the ball caster wheel:
Ball Caster

Moreover, I also started assembling differents parts of the project within Fusion 360.
This is a prototype for the base, primarly focused on the line following and the usage of the motors by including the motor assembly, the caster wheels and the IR Sensor:
Base Top View\
Base Bottom View

After recreating the wanted surface for the base, meaning implementing the fixation holes for all the different components in Inkscape. I started assembling the components so that I could make some motor tests and test the line following system:
- Inkscape sketch\
Inkscape sketch

- Assembly process\
Assembly Top\
Assembly Bottom

This concludes today's session. Next will be testing the motors and the line following as well as implement an ultrasonic sensor to stop the robot if needed.
Note that this is a prototype and changes can be made. The goal of these steps are to test the different functionnalities before building the entire robot in phase 1. After we will do the same process again to achieve our goal for phase 2.

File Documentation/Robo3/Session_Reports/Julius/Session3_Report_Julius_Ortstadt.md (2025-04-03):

# Session 3 Report - 08.12.2023 - Julius Ortstadt

Before today's session I continued the creation of 3D models for different parts of the robot.
The main part being the frame that will later be fixed onto the robot in order to add stability and ease assembly.\
Frame

Additionally, I also made some small changes to other models in order to take into consideration other factors of which I hadn't thought of before.

During today's session my focus was on getting the motors wired up and operational and to do some basic tests. 
However, before I could do that I needed to gather some components (Arduino Mega, power supply, cables, spacers, screws) and prepare mounting points to which I would later mount the H-Bridge as well as the Arduino itself.\
Assembly

I also did some fit checks with a part that I printed. Its goal is to mount the IR sensor on the bottom side of the robot. However, due to some issues, the part needs to be modified a little bit. Here is the new version that I redesigned: \
Modified IR sensor spacer

After that I connected the power to the robot and made some small movement tests which were a little bit complicated due to the short wire of the power supply. I wrote the code for the test with help from the manufacturer of the H-Bridge as well as the different schematics needed in order to correctly wire all the components. The main problem that I encountered, and that uterly took the most time to fix was with the motors. A wheel hub keeps unscrewing itself from the motor shaft due to vibrations. In order to refix it, the entire motor assembly has to be removed. Next session I will try to find a more permanent solution to the problem. Another part that took me a considerable amount of time was to wire up and use the motors since the schematics were a little bit difficult to understand at first.

I also started a new order list in which I listed some components I will need later on:
- A battery 
- A fuse with fuse holder, as it was encouraged to use one by the manufacturer of the H-Bridge

Next session I will try some basic line following as well as object detection. I will finish the design of the new IR sensor spacer as well as the mounting system for the Ultrasonic sensor.

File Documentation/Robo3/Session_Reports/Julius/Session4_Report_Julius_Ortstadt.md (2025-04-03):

# Session 4 Report - 12.12.2023 - Julius Ortstadt

## Before today's session:
- I re-designed the IR sensor spacer in order to correct the mistakes spotted in the previous version, for that I made the design easier and improved the tolerances. While doing this I also cleaned up the sketches in Fusion 360 so that a later modification would be easier. \
New version of IR sensor spacer

- I made some changes to the frame that will support the robot. This included better access to different components, repositioning of the sled elements so that they better fit and have a better overall distribution. I also added the holes for the screws that will allow the frame to be mounted to the robot.\
Modified frame\
Assembled and rendered, the final frame would look like this:\
Rendered frame

- I finished the design of the ultrasonic sensor case.
US Sensor case

- I modelled some other components that will be needed in the final assembly stages, like this screw spacer for instance.
Screw spacer

## During today's session:
- Firstly, before I could start on anything I had to solve the problem of why one wheel was always coming loose. The screws that hold the wheel hub on the motor shaft were shaken loose by vibrations, so I applied some threadlock in order to hold them in place. During later tests, this method seemed to have worked.

- After that I started the print of the new IR spacer and the Ultrasonic sensor case.
After some fit checks, a few adjustments need to be made to the case.

- I then resoldered the cable ends in order to transfer power from the H-bridge to the Arduino so that I would only need one powersupply for the robot.

- I performed some more motor and direction tests since last time I couldn't really make them due to the fact that the wheel kept coming loose.

- I tested the IR sensor to see if it would detect the black line correctly. I then wrote a script to test some basic line following. However, the sensor was to close to the line when fixed to the robot and wouldn't work properly. I tried solving the issue by moving the sensor up and fixing it on the top of the robot after making some holes. However the detection is not working right and I will try to get it to work for the next session. I will also re-do the design of the holding system for this sensor.

Finally, the final assembly:\
Final assembly

For the next session, as I already said, I will review some designs and adapt them accordingly. I will also continue my research on batteries and charging systems and the overall component layout for the robot in order to fit everything in a robot as small as possible.

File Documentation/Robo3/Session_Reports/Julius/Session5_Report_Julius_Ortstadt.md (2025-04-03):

# Session 5 Report - 09.01.2024 - Julius Ortstadt

## Before today's session:
- After final corrections and fit checks I printed all the Ultrasonic sensor cases so they can me mounted onto the robot when ready.\
Sensor cases

- I saw a design flaw in the frame I made in Fusion 360. This would have led to the frame not being able to be assembled correctly. However, I modified it so that when printed, all the parts can be assembled as intended.\
Corrected Frame

- I continued working on the line following with the 5 IR sensor array. I also did some research into how this process can be optimized using PID correction etc.

## During today's session:
- After some tests before today's session I came to the conclusion that working with the 5 IR sensor array would be too complicated since there is no way to change the detection distance. I therefore replaced the array with up to 5 individual sensors that can be used in analog mode and which allow changing the detection distance. I then made some changes to the robot in order to implement this for a test phase and then proceeded to test the line following system with 2 sensors.\
2 sensor line following

- For a test with 3 sensors I want to make a holding element allowing me to position up to 5 sensors on a rail like system. This would allow for a dynamic change of the distance between each sensor if needed. I started modelling this element in Fusion 360.

- I also did some more research into how all the components will fit in a space as small as possible.

- I continued my research into batteries and charging circuits and how the access ports on the robot (for data, power etc.) will be positioned so that everything is as accessible as possible.

## For next session:
Next session we are holding our mid-project presentation. 
Additionnaly, I will try to get the line following working and start using the motor encoders to get more precise movements and better accuracy.

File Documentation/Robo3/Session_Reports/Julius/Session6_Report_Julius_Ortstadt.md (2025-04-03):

# Session 6 Report - 16.01.2024 - Julius Ortstadt

## Before today's session
- After I realized last time that using the 5 IR sensor array wouldn't work properly in this project, I decided to use 5 seperate sensors on which I can change the detection distance via a potentiometer. In order to hold all these sensors, I created a new holding mecanism. This mecanism allows the sensors to be moved on the rail to set the desired distance. Additionally, the sensors will be hold in place via screws and nuts, which are inserted into the rail.\
Line follow module

- I assembled most of the different pieces of the robot in fusion 360 to present it during the mid-term presentation of the robot.\
Robot fusion 360 assembly

## During today's session
- We presented what we did so far on the robot and what is to come.
- I printed the IR sensor rail system and tested mounting the sensors. After some small adjustments, the definitive version will be printed and installed.\
IR sensor rail system
- I started printing a test piece of the frame to see if everything will assemble correctly. If that is the case, I will print the rest of the frame and assembled it.
- We ordered some new components for the final assembly. These components being the LiDAR, inserts for different screw types, right angle connectors for arduino, a fuse holder and two fuses.

## For the next session
- I will do a fit test of the frame and if everything is ok, prepare the necessary files to print the entire thing.
- Print the definitive version of the IR sensor rail.
- Continue coding the line following and start integrating the Ultrasonic sensors.
- Prepare the side pieces of the robot, so that next time I can cut them out using the laser cutter.
- Design the elevated support for the Arduino Mega so that it fits over the H-Bridge of the motor, freeing up the space for the Nvidia Jetson.
- Cut out the discs for the IR sensors so that the screw doesn't come into contact with the PCB.

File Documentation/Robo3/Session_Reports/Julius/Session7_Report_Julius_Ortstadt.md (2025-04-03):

# Session 7 Report - 23.01.2024 - Julius Ortstadt

## Before today's session
- I designed the stacking mechanism which will allow us to put the Arduino above the H-Brigde. This will save space and enable us to keep the main electronics in the back of the robot.\
Picture of Arduino / H-Bridge stack

- I prepared the files for the side panels so that I can make them during today's session.\
Side panels SVG

- I printed the final version of the IR sensor rail.

## During today's session
- I assembled the pieces I printed for the frame. This was only a test fit. I needed to make some small adjustments. The final pieces are in the process of being printed.\
Picture of partial assembly of the frame

- I assembled the IR sensor rail meaning I spaced out the sensors so that there is one tape width between them, I also needed to enlarge the hole through which the sensors will see the ground. I wired all the sensors up so that they can be used. The final wiring will be done later, for now it is just for testing purposes.\
Picture of mounted IR sensors

- By using the laser cutting machine, I prepared the side panels. I installed the ultrasonic sensors and started wiring them up. However, the rest of the frame is needed to hold everything in place.\
Picture of mounted US sensors

- We discussed different strategies of how we will combine the two parts of the robot, meaning the mobile base and the grabbing system. Our main point of focus was how we would create the wired connection between these two parts. We will probably assemble a shield for the Arduino Mega onto which we'll solder connectors. These will enable us to create more stable connections between the wires and the main electronic components. The connection between the two will be achieved using connectors (male and female) like in computers, which have a stronger resistance when pulled upon compared to classic arduino cables.

## For the next session
- The frame will be printed and the assembly can start.

- I'll continue the code for the robot in order to get it operational.

- I'll design the back panel of the robot.

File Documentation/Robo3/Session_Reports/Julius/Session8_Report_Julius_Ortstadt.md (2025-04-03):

# Session 8 Report - 07.02.2024 - Julius Ortstadt

## Before today's session
- I wrote a test programm for one of the motor encoders to fully understand how they work and how I will eventually use their data to make a PID corrector for the robot.

- I designed the fuse holder I ordered so that I can put it in the 3D model of the robot and later easier design the entire back panel.\
Fuse holder

## During today's session
- I received the components I ordered. This enabled me to really progress in the assembling process.

- I prepared the base plate for installation of the frame and the stack. Meaning I had to mark the new holes, drill them and unscrew other components so that all can be assembled.

- I assembled the frame. In order to do that I had to make some small adjustments like deepening the holes for the screws and put in the inserts.\
Frame assembly

- I printed and assembled the "stack" which is the Arduino stacked on top of the H-Bridge. This will allow us to save space and also fit the Nvidia Jetson in the back of the robot.\
Stack

- I started soldering the shield for the Arduino Mega. This will allow us to completely remove simple Arduino connectors and therefore only use soldered connections or those with screws.\
Arduino Mega Shield progress

## For the next session
- I will redesign some parts of the stack for the Arduino and the H-Bridge since, during installation, there were some fiting problems.

- I will continue thinking about the placement of the components on the Arduino shield.

- I will start designing the component that will eventually hold the connectors. These connectors will be the interface between the movable base and the grabbing system.

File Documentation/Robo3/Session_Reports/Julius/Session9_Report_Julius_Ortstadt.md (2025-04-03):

# Session 9 Report - 13.02.2024 - Julius Ortstadt

## Before today's session
- I made some changes to the stacking system between the Arduino and the H-Bridge.\
New stacker

## During today's session
- I started the print of the stacker. Since it wasn't a very long print, I was able to install it on the robot. Since everything works, this will be the final version.\
Installed stack

- I modelled, in fusion 360, the main power plug for the robot so that I can use it in the 3D model of the robot.\
Power plug

- I quickly modelled a spacer needed to position the Nvidia Jetson correctly in the 3D model.\
Spacer

- I inserted the power plug and the fuse holder into the 3D model of the robot and started designing the back panel. This can be subject to change, it is however unlikely, except if we need to make a very big change to the design.\
Back panel 3D

- I then cut out the back panel in 5mm CP wood using the laser cuter. I then inserted the plug and the fuse holder and installed everything in the robot.\
Installed back panel with components

- The next step was to solder the cables to the different components and change some of the wiring for easier access and esthetic. This includes shifting the power supply of the Arduino from the front port to the Vin pin and GND.\
Soldered cables and new power lines for arduino

- I also made some adjustments to the 3D model of the robot. These being the new placement of some components (just with more safety margins).\
New robot render

## For the next session
- I will start thinking about the connector plate as I said last time. This also includes the mecanism that will allow us to "fuse" the movable base and the grabbing system together. We also need to leave some space between the two for the LiDAR system later on in the project.

- I will make a sketch of how the different components still needed will be implemented on the Arduino shield.

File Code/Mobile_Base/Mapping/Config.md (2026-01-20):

# Setup of the Mapping workspace for the Grabby project

---

**Project:** Grabby\
**Author:** Julius Ortstadt\
**Date:** 27.11.2025\
**Description:** Information about the setup and configuration of the mapping workspace for the Grabby robot.

---

## Table of Contents
- [Setup of the Mapping workspace for the Grabby project](#setup-of-the-mapping-workspace-for-the-grabby-project)
  - [Table of Contents](#table-of-contents)
  - [Information](#information)
  - [Specifications](#specifications)
    - [Information: Teleop package](#information-teleop-package)
    - [Information: Cartographer package](#information-cartographer-package)
  - [Setup](#setup)
    - [Workspace](#workspace)
    - [Teleop package](#teleop-package)
    - [Joystick package](#joystick-package)
    - [LiDAR package](#lidar-package)
      - [Testing in the terminal](#testing-in-the-terminal)
      - [Testing with RVIZ](#testing-with-rviz)
    - [Cartographer package](#cartographer-package)
      - [Installation](#installation)
      - [Package](#package)
    - [IMU package](#imu-package)
      - [Installation](#installation-1)
      - [Testing](#testing)
  - [References](#references)

## Information
The launch commands can be found in the **Info** file of this directory.
This file describes the configuration and setup of the various packages in the workspace to achieve mapping capabilities with the robot.

## Specifications
**Development boards:** RaspberryPi 5 / Arduino Nano\
**ROS Distribution:** ROS1 Melodic in Docker container\

### Information: Teleop package 
**Package Name:** teleop_robot\
**Node Name:** teleop_robot\
**Topics:**
  - Subscribes to */joy*
  - Published on */cmd_serial*

### Information: Cartographer package 
**Package Name:** cartographer_pkg
- **Launch files:**
  - *mapping_basic.launch* 
    - Load robot description (*grabby_robot.urdf*)
    - Start robot state publisher
    - Start RPLIDAR node (specify the serial port / default is set to *ttyUSB0*)
    -  Start Google Cartographer node with custom configuration file (uncomment the desired configuration in the *mapping.launch* launch file):
       -  Only LiDAR: *mapping_basic.lua*
       -  LiDAR + IMU: *mapping_imu.lua*
       -  LiDAR + IMU + Odometry: *mapping_imu_odom.lua*
  - *map_visualization.launch*
    - Start Rviz with custom configuration (*demo.rviz*)   

## Setup
### Workspace
- Create a folder
```bash
mkdir -p ./mapping_ws/src
cd mapping_ws
```
- Build the workspace
```bash
catkin_make
```
- Source the workspace
```bash
source devel/setup.bash
```
- Auto-source the workspace at container startup by adding the following to the **.bashrc**
```bash
nano ~/.bashrc
source /ros_shared/mapping_ws/devel/setup.bash
```

### Teleop package
In the previously created workspace, create a new package that will hold the necessary nodes for the teleoperation.
- Go to the source folder of the workspace
```bash
cd mapping_ws/src
```
- Create a new package with the necessary dependencies
```bash
catkin_create_pkg teleop_robot roscpp rospy sensor_msgs geometry_msgs
```
- Go to the source folder and add the **controller_teleop_node.cpp** file
```bash
cd teleop_robot/src
touch controller_teleop_node.cpp
```
- Go to the root of the package and modify the **CMakeLists.txt** by adding the following at the right place. The comments help localize where.
```cmake
add_executable(teleop_robot src/controller_teleop_node.cpp)

target_link_libraries(teleop_robot ${catkin_LIBRARIES})
```
- At the root of the package, create a new folder named **launched** which will hold the launch file for the teleoperation and create the **teleop.launch** file
```bash
mkdir launch
cd launch
touch teleop.launch
```

### Joystick package
Install the joystick package to control the robot using a PS4 dualshock 4 controller.

- Give information about the ROS repositories
```bash
sudo sh -c 'echo "deb http://packages.ros.org/ros/ubuntu $(lsb_release -sc) main" > /etc/apt/sources.list.d/ros-latest.list'
```
- Install **curl** if not already done.
```bash
sudo apt install curl
```
- Add the keys
```bash
curl -s https://raw.githubusercontent.com/ros/rosdistro/master/ros.asc | sudo apt-key add -
```
- Update
```bash
sudo apt update
```
- Install the package
```bash
sudo apt install ros-melodic-joy
```
- Run the node to test the installation.
```bash
rosrun joy joy_node
```

### LiDAR package
Install the RPLiDAR ROS package to use the LiDAR for mapping.
- Go to the **src** folder of the workspace
- Clone the repository
```bash
sudo git clone https://github.com/Slamtec/rplidar_ros.git
```
- Go back to the root of the workspace and build the workspace
```bash
catkin_make
```

#### Testing in the terminal 
- Start *roscore* in one terminal
- In another terminal, launch the LiDAR node. The default port is /dev/ttyUSB0. If another port has been assigned, use the argument: 
```bash
roslaunch rplidar_ros rplidar_a1.launch
```
- In a new terminal, the **/scan** topic should now be displayed when typing:
```bash
rostopic list
```
- The raw data can be displayed with:
```bash
rostopic echo /scan
```

#### Testing with RVIZ
To visualize the data in RVIZ, do the previous steps as for the terminal but instead of the *echo* command:
- Start rviz by typing *rviz* in the terminal
- Go to *Add* -> *By topic* -> *LaserScan*
- Under the topic, select */scan*
- Change the *fixed frame* from *map* to *laser*

### Cartographer package
#### Installation
To install Google cartographer, either use the prebuilt packages (done here) or build from source (described on the [Google cartographer documentation](https://google-cartographer-ros.readthedocs.io/en/latest/compilation.html)).

- Run:
```bash
sudo apt-get install ros-melodic-cartographer ros-melodic-cartographer-ros ros-melodic-cartographer-ros-msgs ros-melodic-cartographer-rviz
```

#### Package
To create the package, run the following commands:
```bash
cd mapping_ws/src
catkin_create_pkg cartographer_pkg cartographer_ros roscpp sensor_msgs nav_msgs tf2_ros urdf
cd mapping_ws
catkin_make
source devel/setup.bash
```

### IMU package
#### Installation
- Connect the IMU following the [pinout](https://pinout.xyz/) of the Pi.

  | BNO055 Pin | Pi Pin Number            |
  |------------|--------------------------|
  | Vin        | 3.3V Power               |
  | GND        | Ground (GND)             |
  | SDA        | I2C SDA                  |
  | SCL        | I2C SCL                  |

- After booting the RPi5, test if the IMU is detected. The command should show the adress of the IMU.
```bash
sudo i2cdetect -r -y 1
```
- Install the libi2c-dev library
```bash
sudo apt-get install libi2c-dev
```
- In the **src** folder of the workspace, clone the package
```bash
git clone https://github.com/dheera/ros-imu-bno055.git
```
- Go back to the root of the workspace and build
```bash
catkin_make
```

#### Testing
- Install the ROS IMU plugin so that the IMU can be visualized in rviz
```bash
sudo apt-get install ros-melodic-rviz-imu-plugin
```
- In a new docker terminal
```bash
roslaunch imu_bno055 imu.launch
```
- Check if the **/imu/data** topic is there
```bash
rostopic list
```
- Start RVIZ
```bash
rviz
```
- Change the fixed frame to imu.
- Click the Add button in the bottom left.
- Click imu under rviz_imu_plugin. 
- Click OK.
- Change the topic of the imu to /imu/data.
- Move the BNO055 around, and the axes should move. 
  - The red line is the x-axis
  - The green line is the y-axis
  - The blue line is the z-axis.

## References
- ROS1 Melodic: Create a workspace
https://wiki.ros.org/catkin/Tutorials/create_a_workspace

- ROS1 Melodic: Create a package
https://wiki.ros.org/ROS/Tutorials/CreatingPackage

- RPLIDAR GitHub repository
https://github.com/Slamtec/rplidar_ros

- Google cartographer "build from source" documentation
https://google-cartographer-ros.readthedocs.io/en/latest/compilation.html

- How to Publish IMU Data Using ROS and the BNO055 IMU Sensor
https://automaticaddison.com/how-to-publish-imu-data-using-ros-and-the-bno055-imu-sensor/

- ROS Standard Units of Measure and Coordinate Conventions
https://www.ros.org/reps/rep-0103.html

- RaspberryPi Pinout
https://pinout.xyz/

- Adafruit 9-DOF Absolute Orientation IMU Fusion Breakout - BNO055
https://www.adafruit.com/product/2472

- ROS1/ROS2 C++ driver for Bosch BNO055 IMU (I2C)
https://github.com/dheera/ros-imu-bno055

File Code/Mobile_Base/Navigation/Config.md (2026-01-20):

# Setup of the Navigation workspace for the Grabby project

---

**Project:** Grabby\
**Author:** Julius Ortstadt\
**Date:** 17.01.2026\
**Description:** Information about the setup and configuration of the navigation workspace for the Grabby robot.

---

## Table of Contents
- [Setup of the Navigation workspace for the Grabby project](#setup-of-the-navigation-workspace-for-the-grabby-project)
  - [Table of Contents](#table-of-contents)
  - [Information](#information)
  - [Specifications](#specifications)
  - [Setup](#setup)
    - [Workspace](#workspace)
    - [LiDAR package](#lidar-package)
      - [Testing in the terminal](#testing-in-the-terminal)
      - [Testing with RVIZ](#testing-with-rviz)
    - [IMU package](#imu-package)
      - [Installation](#installation)
      - [Testing](#testing)
    - [Localization data publisher package](#localization-data-publisher-package)
      - [Information](#information-1)
      - [Setup](#setup-1)
    - [Robot pose ekf package](#robot-pose-ekf-package)
      - [Installation](#installation-1)
    - [Navigation package](#navigation-package)
      - [Information](#information-2)
      - [Installation and Setup](#installation-and-setup)
  - [Troubleshooting](#troubleshooting)
    - [Frame misalignment](#frame-misalignment)
  - [References](#references)

## Information
The launch commands can be found in the **Info** file of this directory.
This file describes the configuration and setup of the various packages in the workspace to achieve navigation capabilities with the robot.

## Specifications
**Development boards:** RaspberryPi 5 / Arduino Nano\
**ROS Distribution:** ROS1 Melodic in Docker container\

## Setup
### Workspace
- Create a folder
```bash
mkdir -p ./navigation_ws/src
cd navigation_ws
```
- Build the workspace
```bash
catkin_make
```
- Source the workspace
```bash
source devel/setup.bash
```
- Auto-source the workspace at container startup by adding the following to the **.bashrc**
```bash
nano ~/.bashrc
source /ros_shared/navigation_ws/devel/setup.bash
```

### LiDAR package
Install the RPLiDAR ROS package to use the LiDAR for mapping.
- Go to the **src** folder of the workspace
- Clone the repository
```bash
sudo git clone https://github.com/Slamtec/rplidar_ros.git
```
- Go back to the root of the workspace and build the workspace
```bash
catkin_make
```

#### Testing in the terminal 
- Start *roscore* in one terminal
- In another terminal, launch the LiDAR node. The default port is /dev/ttyUSB0. If another port has been assigned, use the argument: 
```bash
roslaunch rplidar_ros rplidar_a1.launch
```
- In a new terminal, the **/scan** topic should now be displayed when typing:
```bash
rostopic list
```
- The raw data can be displayed with:
```bash
rostopic echo /scan
```

#### Testing with RVIZ
To visualize the data in RVIZ, do the previous steps as for the terminal but instead of the *echo* command:
- Start rviz by typing *rviz* in the terminal
- Go to *Add* -> *By topic* -> *LaserScan*
- Under the topic, select */scan*
- Change the *fixed frame* from *map* to *laser*

### IMU package
#### Installation
- Connect the IMU following the [pinout](https://pinout.xyz/) of the Pi.

  | BNO055 Pin | Pi Pin Number            |
  |------------|--------------------------|
  | Vin        | 3.3V Power               |
  | GND        | Ground (GND)             |
  | SDA        | I2C SDA                  |
  | SCL        | I2C SCL                  |

- After booting the RPi5, test if the IMU is detected. The command should show the adress of the IMU.
```bash
sudo i2cdetect -r -y 1
```
- Install the libi2c-dev library
```bash
sudo apt-get install libi2c-dev
```
- In the **src** folder of the workspace, clone the package
```bash
git clone https://github.com/dheera/ros-imu-bno055.git
```
- Go back to the root of the workspace and build
```bash
catkin_make
```

#### Testing
- Install the ROS IMU plugin so that the IMU can be visualized in rviz
```bash
sudo apt-get install ros-melodic-rviz-imu-plugin
```
- In a new docker terminal
```bash
roslaunch imu_bno055 imu.launch
```
- Check if the **/imu/data** topic is there
```bash
rostopic list
```
- Start RVIZ
```bash
rviz
```
- Change the fixed frame to imu.
- Click the Add button in the bottom left.
- Click imu under rviz_imu_plugin. 
- Click OK.
- Change the topic of the imu to /imu/data.
- Move the BNO055 around, and the axes should move. 
  - The red line is the x-axis
  - The green line is the y-axis
  - The blue line is the z-axis.

### Localization data publisher package
#### Information
- **Package Name:** localization_data_pub
- **Publishes:**
  - */initial_2d* (geometry_msgs/PoseStamped)
  - */goal_2d topic* (geometry_msgs/PoseStamped)
- **Subscribes:**
  - */initialpose* (geometry_msgs/PoseWithCovarianceStamped)
  - */move_base_simple/goal* (geometry_msgs/PoseStamped)

#### Setup
- In the workspace **src** folder
```bash
catkin_create_pkg localization_data_pub rospy roscpp std_msgs tf tf2_ros geometry_msgs sensor_msgs nav_msgs
```
- Go back to the workspace root and build
```bash
catkin_make
```
- In the source of this package, add the files **ekf_odom_pub.cpp** and **rviz_click_to_2d.cpp**
- Modify the *CMakeLists.txt* (the completed file is provided here).
- The launch file is optional as it will be handled by the navigation stack which holds the mail launch file.

### Robot pose ekf package
#### Installation
- Run the command
```bash
sudo apt-get install ros-melodic-robot-pose-ekf
```

### Navigation package
#### Information
- **Package Name:** nav_stack
ROS Architecture

* `Base controller`
The base controller is implemented in the script **motor_controller_diff_drive_2.ino**, which must be uploaded to the Arduino before launching the package. The controller receives velocity commands from the `move_base` node and converts them into PWM signals to drive the motors. It also publishes motor encoder ticks for odometry computation. Additionally, the controller includes speed correction mechanisms to compensate for motor mismatches and ensure straight-line motion.

* `Costmap configuration "param"`
  * `base_local_planner_params.yaml`
These parameters define the motion constraints and behavior of the robot’s local planner. They specify limits for linear and angular velocities, acceleration bounds, and goal tolerances. The robot is configured as a non-holonomic system, meaning lateral motion is not permitted. The `meter_scoring` parameter ensures that path costs are evaluated in meters.

  * `costmap_common_params.yaml`
These settings apply to both the global and local costmaps, defining the robot’s footprint, sensor range for obstacle detection, and costmap update frequencies. The footprint is explicitly defined with padding for safety. 
Three primary layers are used:

    - **Static Layer:** Uses a pre-defined map.  
    - **Obstacle Layer:** Updates obstacles dynamically from sensor data.  
    - **Inflation Layer:** Expands obstacle areas to maintain safe distances and prevent collisions.

  * `global_costmap_params.yaml`
  The global costmap represents the entire environment relative to the `odom` frame. It updates at the specified frequency with the specified resolution and is primarily used for long-term path planning.

  * `local_costmap_params.yaml`
The local costmap is a smaller, rolling window centered on the robot, used for short-term obstacle avoidance. It updates at the specified frequency, with the specified inflation radius. Sensor data is integrated dynamically, and the costmap maintains a 1×1 meter window for efficient navigation.

* `Launch file "nav.launch"`
All information about the launch file is documented in the file comments. A brief overview is provided below.

  * `State publisher`
Loads the robot description from the URDF file.

  * `LiDAR Launch`
Starts the LiDAR node using either the default serial port (**/dev/ttyUSB1**) or a user-specified port. The node relies on the ROS package provided by RPLIDAR.

  * `Odometry Launch`
Starts the wheel odometry node, which converts wheel encoder ticks into odometry data. The IMU data publisher is also launched, and an Extended Kalman Filter (EKF) fuses the wheel and IMU data for reliable SLAM input.

  * `Wheel Encoder Tick Publisher and Base Controller`
Starts serial communication with the Arduino running the base controller script. The serial port can be set via an argument or defaults to **/dev/ttyUSB0**.

  * `Mapping Information`
Launches the initial pose and goal publisher for setting start and end positions in RViz. RViz is also launched for visualization. The map file and map server are loaded to allow the robot to use a pre-existing map.

  * `Move Base Node`
Converts SLAM output into velocity commands for the Arduino, which publishes them to a topic for execution by the base controller.

  * `AMCL Configuration`
Provides an example configuration of AMCL (Adaptive Monte Carlo Localization) for differential drive robots. AMCL is a probabilistic 2D localization system for mobile robots.

#### Installation and Setup
- Install the navigation stack
```bash
sudo apt-get install ros-melodic-navigation
```
- In the **src** folder of the workspace, create a package
```bash
catkin_create_pkg navstack_pub rospy roscpp std_msgs tf tf2_ros geometry_msgs sensor_msgs nav_msgs move_base
```
- Go to the root of this new package
  - Create a **param** folder
  - Create a **launch** folder
  - Create a **rviz** folder
  - Create a **urdf** folder
- Copy the files from this repo to their respective folders
- Modify the **CMakeLists.txt** and the **package.xml** files with the ones in this repository
- Go back to the root of the workspace and build the workspace
```bash
catkin_make
```

## Troubleshooting 
### Frame misalignment
If there are problems with the frames and the tf transforms, check the tf tree.
- While the package is running and the **initial_pose** and **goal_pose** have been set, run:
```bash
rosrun tf view_frames
```
- When the command is finished:
```
evince frames.pdf
```
**Note:** If *evince* is not installed, run `sudo apt install evince`.

The resulting frame should look like this:
[TF tree]()

## References
- ROS1 Melodic: Create a workspace
https://wiki.ros.org/catkin/Tutorials/create_a_workspace

- ROS1 Melodic: Create a package
https://wiki.ros.org/ROS/Tutorials/CreatingPackage

- RPLIDAR GitHub repository
https://github.com/Slamtec/rplidar_ros

- How to Publish IMU Data Using ROS and the BNO055 IMU Sensor
https://automaticaddison.com/how-to-publish-imu-data-using-ros-and-the-bno055-imu-sensor/

- ROS Standard Units of Measure and Coordinate Conventions
https://www.ros.org/reps/rep-0103.html

- How to Set Up the ROS Navigation Stack on a Robot
https://automaticaddison.com/how-to-set-up-the-ros-navigation-stack-on-a-robot/

- How to Create an Initial Pose and Goal Publisher in ROS
https://automaticaddison.com/how-to-create-an-initial-pose-and-goal-publisher-in-ros/

- RaspberryPi Pinout
https://pinout.xyz/

- robot_pose_ekf
https://wiki.ros.org/robot_pose_ekf

- Adafruit 9-DOF Absolute Orientation IMU Fusion Breakout - BNO055
https://www.adafruit.com/product/2472

- ROS1/ROS2 C++ driver for Bosch BNO055 IMU (I2C)
https://github.com/dheera/ros-imu-bno055

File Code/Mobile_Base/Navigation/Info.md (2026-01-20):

# General information about the Navigation Workspace

---

**Project:** Grabby\
**Author:** Julius Ortstadt\
**Date:** 17.01.2026\
**Description:** General information about the workspace and usefull commands.

---

## Table of Contents
- [General information about the Navigation Workspace](#general-information-about-the-navigation-workspace)
  - [Table of Contents](#table-of-contents)
  - [Information](#information)
  - [Specifications](#specifications)
  - [Commands](#commands)

## Information
* Details on each package and setup can be found in the **Config.md** file of this directory. 
* Make sure that the **motor_controller_diff_drive_2.ino** programm is loaded on the RaspberryPi. It can be found in the *Base_controller* folder.

## Specifications
**Development boards:** RaspberryPi 5 / Arduino Nano\
**ROS Distribution:** ROS1 Melodic in Docker container\

## Commands
- Workspace: `navigation_ws`
    - Make (at workspace root)
    ```
    catkin_make
    ```
    - Source (at workspace root)
    ```bash
    source devel/setup.bash
    ```
- Launch **Navigation stack**
    - **Basic launch command:** with 
      - Default `map_file`: /ros_shared/maps/map.yaml
      - Default `serial_port_arduino`: /dev/ttyUSB0
      - Default `serial_port_lidar`: /dev/ttyUSB1
    ```bash
    roslaunch navstack_pub nav.launch
    ```
    - **Launch command:** with arguments (all or some can be specified)
    ```bash
    roslaunch navstack_pub nav.launch map_file:=/ros_shared/maps/map_d103_ros.yaml serial_port_arduino:=/dev/ttyUSB0 serial_port_lidar:=/dev/ttyUSB1
    ```
**Note:** The map needs to be a ROS map (a *.yaml* and a *.pgm* file / specify the *.yaml* file in the parameter). The instructions for mapping and conversion can be found in the documentation for the mapping procedure.

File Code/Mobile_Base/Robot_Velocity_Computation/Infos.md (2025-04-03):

# Velocity Compute
#### Author: Julius Ortstadt

Here you can find an Arduino code to control the robot with different PWM values and then retrieve all the necessary information via the bluetooth serial connection. 
However, manual measurements for verification are encouraged although not necessary.

Also, an excel sheet can be found where the measured values can be entered in order to get the coefficients for a least-squares curve fitting using the batch approach. 
This will yield a relation between the speed in m/s of the robot and the applied PWM signal.

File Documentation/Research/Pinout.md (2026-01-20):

# Pinout information for the project 

---

**Project:** Grabby\
**Author:** Julius Ortstadt\
**Date:** 19.01.2026\
**Description:** Pinout information for the project.

---

## Arduino Nano Pinout for Motors

### Motor 1

| Signal | Function / Description | Arduino Nano Pin |
|---|---|---|
| IN1 | Motor direction control | D4 |
| IN2 | Motor direction control | D7 |
| ENA | Motor enable (PWM) | D5 (PWM) |
| Encoder A | Encoder channel A (Interrupt) | D2 |
| Encoder B | Encoder channel B | D8 |
| Encoder GND | Ground | GND |
| Encoder VCC | Power | +5V |

### Motor 2

| Signal | Function / Description | Arduino Nano Pin |
|---|---|---|
| IN3 | Motor direction control | D9 |
| IN4 | Motor direction control | D10 |
| ENB | Motor enable (PWM) | D6 (PWM) |
| Encoder A | Encoder channel A (Interrupt) | D3 |
| Encoder B | Encoder channel B | D11 |
| Encoder GND | Ground | GND |
| Encoder VCC | Power | +5V |

## Arduino Nano Pinout for Power Information

### Screen

| Signal | Description | Arduino Nano Pin |
|---|---|---|
| GND | Ground | GND |
| VCC | Power | 5V |
| SDA | I2C Data | A4 |
| SCL | I2C Clock | A5 |

### Voltage Sensor – 12V

| Signal | Description | Arduino Nano Pin |
|---|---|---|
| GND | Ground | GND |
| IN | Voltage input | 12V |
| OUT | Analog output | A1 |

### Voltage Sensor – 5V

| Signal | Description | Arduino Nano Pin |
|---|---|---|
| GND | Ground | GND |
| IN | Voltage input | 5V |
| OUT | Analog output | A0 |

### Current Sensor – 12V

| Signal | Description | Arduino Nano Pin |
|---|---|---|
| GND | Ground | GND |
| VCC | Power | 5V |
| OUT | Analog output | A3 |

### Current Sensor – 5V

| Signal | Description | Arduino Nano Pin |
|---|---|---|
| GND | Ground | GND |
| VCC | Power | 5V |
| OUT | Analog output | A2 |

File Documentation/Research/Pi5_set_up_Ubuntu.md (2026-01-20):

# Initial set up of the RPi5 with Ubuntu Server for the Grabby Project

---

**Project:** Grabby\
**Author:** Julius Ortstadt\
**Date:** 08.11.2025\
**Description:** This is a practical guide on how to set up the RaspberryPi 5 for the Grabby project. Used is Ubuntu 24.04.3 LTS Server to support ROS2 Jazzy and ROS1 Melodic in a Docker container and connect to it with no need of a screen. 

---

## Table of Contents
- [Initial set up of the RPi5 with Ubuntu Server for the Grabby Project](#initial-set-up-of-the-rpi5-with-ubuntu-server-for-the-grabby-project)
  - [Table of Contents](#table-of-contents)
  - [Login credentials](#login-credentials)
  - [Connect to the RPi with FileZilla](#connect-to-the-rpi-with-filezilla)
  - [Hardware Information](#hardware-information)
  - [Software Information](#software-information)
  - [Practical Information](#practical-information)
  - [OS Installation on the RPi5](#os-installation-on-the-rpi5)
  - [Set up NoMachine](#set-up-nomachine)
  - [Minicom](#minicom)
  - [Arduino IDE](#arduino-ide)
  - [WiFi config](#wifi-config)
  - [Troubleshooting](#troubleshooting)
    - [NoMachine](#nomachine)
    - [Configure the Ethernet port](#configure-the-ethernet-port)
    - [SSH problems after firewall reset](#ssh-problems-after-firewall-reset)
    - [SSH problem for Ethernet connection](#ssh-problem-for-ethernet-connection)
  - [References](#references)

## Login credentials
**Device name:** rpi\
**Username:** rpi\
**Password:** rpi 

## Connect to the RPi with FileZilla 
**Server:** sftp://<PI_IP>\
**Username:** rpi\
**Password:** rpi

## Hardware Information
- RaspberryPi 5 with 16Gb RAM
- Official RaspberryPi power supply
- 64Gb micro-SD card 
- micro-SD card adapter to SD if no micro-SD slot available on the PC

## Software Information
For this process, different software will be used. If relevant, the use and set up of each will be detailed in the relevant section of this documentation.

- **RaspberryPi Imager** for OS installation.
- **FileZilla** for file transfers between the RPi and another PC (based on SSH).
- **Advanced IP Scanner** to determine the IP address of a device in a network. Note that any other IP scan software can be used.
- **NoMachine** to have a remote desktop connection between a PC and the RPi and use it in headless mode

## Practical Information
For better readability, the following will be done:
- RaspberryPi (5) will be referred to as RPi (5)

## OS Installation on the RPi5
An official guide can be found on the [Ubuntu Tutorial page](https://ubuntu.com/tutorials/how-to-install-ubuntu-on-your-raspberry-pi#1-overview).
Since we install Ubuntu Server, there is no need to diretly connect to a screen with HDMI and a mouse and keyboard etc. The Pi will directly be setup in headless mode.
- Use of **RaspberryPi Imager**
    - Choose the RPi model
    - Choose the OS. In this case, Ubuntu 24.04.3 LTS Server.
    - Select the SD Card
    - In the Advanced Settings (after clicking **Next**)
        - Set up the username and password
        - Set up the Wi-Fi credentials if available
        - Enable SSH support
- When done, insert the micro-SD card into the RPi and connect it to power to boot it.
- Wait a few seconds for the RPi to do the first boot, connect to the internet etc.
- Using **Advanced IP Scanner**, find the IP of the Pi in the current network. Note that the PC and the Pi need to be in the same network.
- Connect via SSH with Windows Powershell
    ```bash
    ssh username@hostname_or_IP
    ```
    Here this will be: 
    ```bash
    ssh rpi@rpi
    ```

Since Ubuntu Server is used, no desktop is available. However, one will be needed to visualize the mapping and navigation procedure.
To do that, a desktop can be installed.
- When the connection via SSH is established, ensure the packages are updated to the latest version.
    ```bash
    sudo apt update
    sudo apt upgrade
    ```
- Chosen was XUbuntu as the desktop environment but other more lightweight choices exist like LUbuntu:
    ```bash
    sudo apt install xubuntu-desktop
    ```
- When installation is finished, reboot the Pi:
    ```bash
    sudo reboot
    ```

## Set up NoMachine
To connect to the remote desktop that was just installed, NoMachine will be used. 
Here is the detailled procedure to get everything up and running:
- From the [official NoMachine website](https://www.nomachine.com/) on the PC, download the latest installer for the ARM64 64-bit architecture (which is the one the Pi has).
At the time of writting, this was: **NoMachine for ARM DEB (arm64) / Version 9.2.18_3 for Ubuntu, Debian**. It is important to choose the one for Ubuntu.
    - Go to **Home -> Download -> NoMachine for ARM**
- In the home folder, a download folder was created to where the installer file will be copied:
    ```bash
    mkdir Downloads
    ```
- Transfer the file with FileZilla to the Pi.
  - Server: sftp://<Pi_IP>
  - Username: <Pi_Username>
  - Password: <Pi_Password>  
- Install the package on the Pi through SSH
    ```bash
    sudo dpkg -i nomachine_9.x.x_x_arm64.deb
    ```
- Run this command to fix any broken installation
    ```bash
    sudo apt --fix-broken install -y
    ```
- When this is done, check and start the NoMachine server
    ```bash
    sudo systemctl status nxserver
    sudo systemctl enable nxserver
    sudo systemctl start nxserver
    ```
The first command should already show something like **active (running)**. If so, the other commands don't need to be executed.

- Connect from the PC:
  - Install NoMachine on the PC by downloading the latest installer for the PC's OS.
  - Open NoMachine client on the PC.
  - Follow the instruction pages.
  - Connect to the Pi using its IP.
  - Log in with the Pi's username and password.
  - If NoMachine throws an error that no display was found and wants to create a virtual one, say **yes**.
  - If all went well, the desktop should appear. If not, go to the **Troubleshooting** section of this guide.

## Minicom
Install Minicom on the RPi5 to monitor traffic on the Serial port.
```bash
sudo apt install minicom
```

## Arduino IDE
To install the Arduino IDE (Legacy Edition) on the RPi5, follow the steps below:
- Go to the [official arduino website](https://www.arduino.cc/en/software/#ide) and download the *.tar.xz* file for the **ARM64 architecture (aarch64)**.
- Transfer the file to the RPi using FileZilla
- Go to the location of the file on the RPi and extract it.
```bash
tar -xf arduino-1.8.19-linuxaarch64.tar.xz
```
- Go inside the newly created folder
```bash
cd arduino-1.8.19/
```
- Install
```bash
sudo ./install.sh
```
- When done, an icon will appear under **Applications** on the desktop environment. The Arduino IDE is now ready to be used.

## WiFi config
If it is necessary to add a new WiFi network so that the Pi automatically connects to it, the following can be done if **netplan** is used.
1. Connect via SSH with the Pi (done here using an ethernet cable)
2. Edit the netplan file:
```bash
sudo nano /etc/netplan/50-cloud-init.yaml
```
3. Update it like this (example adds a second Wi-Fi):
```yaml
network:
  version: 2
  renderer: networkd
  ethernets:
    eth0:
      dhcp4: true
      optional: true
  wifis:
    wlan0:
      optional: true
      dhcp4: true
      access-points:
        "Network1_Name":
          hidden: true
          auth:
            key-management: "psk"
            password: "password1"
        "Network2_Name":
          auth:
            key-management: "psk"
            password: "password2"
```
* `hidden: true` is only needed if the SSID is hidden
* Netplan will automatically connect to **any available known network**

4. Apply the changes
```bash
sudo netplan generate
sudo netplan apply
```
5. Verify
```bash
ip a show wlan0
iw dev wlan0 link
```

**Note**
* It is possible to set WiFi priority:
Netplan uses signal strength by default, but it is possible to **force priority**:
(Higher number = preferred network)

```yaml
access-points:
  "Powerphone":
    priority: 100
    hidden: true
    auth:
      key-management: "psk"
      password: "1"
  "MyHomeWiFi":
    priority: 50
    auth:
      key-management: "psk"
      password: "MySecurePassword"
```

## Troubleshooting
### NoMachine
If the connection to the Pi with NoMachine showed an error prompting to logout because a fatal error occured, the issue will be resolved in this section.
The config of NoMachine needs to be modified because by default it tries to start **GNOME** but the installed environment uses **Xfce**. This needs to be changed in the config and it should all work.
- Edit the NoMachine config
    ```bash
    sudo nano /usr/NX/etc/node.cfg
    ```
- Find the line
    ```bash
    DefaultDesktopCommand "/etc/X11/Xsession gnome-session"
    ```
- Change it to
    ```bash
    DefaultDesktopCommand "/usr/bin/startxfce4"
    ```
- Save and exit the file
- Restart NoMachine
    ```bash
    sudo systemctl restart nxserver
    ```
- Connect again with NoMachine
    - If it asks to create a new display -> **Yes**.

The Xfce desktop should now appear.

### Configure the Ethernet port
If an Ethernet cable is plugged in, by default it should get an IP address and auto-configure the port. However, if this is not the case, the steps below solve the problem that occured in the scope of this project.
Note that the cable connection is between the Pi and a router, not a PC.
In the projects case, the Ethernet port was not configured and therefore no IP address was assigned.

- SSH into the Pi. This supposes that a wireless connection (over WiFi can be established with the Pi)
- Check the IP addresses
    ```bash
    ip a
    ```
- Here the result was:
    ```bash
    2: eth0: <BROADCAST,MULTICAST> mtu 1500 qdisc noop state DOWN group default qlen 1000 link/ether 88:a2:9e:26:76:85 brd ff:ff:ff:ff:ff:ff
    ```
    Showing that the Ethernet was DOWN.
- Check whether Ethernet is managed by Netplan
    ```bash
    ls /etc/netplan
    ```
    It should return something like **50-cloud-init.yaml**
- Open this file
    ```bash
    sudo nano /etc/netplan/50-cloud-init.yaml
    ```
- Ensure that **eth0** is defined. If not, add this:
    ```yaml
    network:
      version: 2
      renderer: networkd

      ethernets:
        eth0:
          dhcp4: true
          optional: true
    ```
    **Note:** Since this is a *.yaml* file, formatting is very important. Tabs can't be used, everything needs to be spaces. Each indentation is actually 2 spaces.
- Save and exit the file.
- Apply the changes
    ```bash
    sudo netplan apply
    ```
    Or if there should be a debug output:
    ```bash
    sudo netplan --debug apply
    ```
- Check if Ethernet came UP
    ```bash
    ip a
    ```
    There should now be a line like this:
    ```bash
    2: eth0: <BROADCAST,MULTICAST,UP,LOWER_UP> ...
        inet 192.168.x.x/24
    ```
    This now means that everything is up and running.

### SSH problems after firewall reset
If the firewall was deactivated and reactivated it may happen that the SSH port is blocked. 
This entry gives a step-by-step guide on resolving this issue.

**Note:** As no SSH connection was available, this procedure was done through the NoMachine remote desktop connection as it is another protocol (NX) and was still working. 

- Check the status of the SSH port
    ```bash
    sudo systemctl status ssh
    ```
    If it says **inactive** or **failed**, the connection needs to be re-established.
- To re-activate the SSH:
    ```bash
    sudo systemctl enable ssh
    ```
- Check the status. It should now say **active** or something similar.
    ```bash
    sudo systemctl start ssh
    ```
The SSH connection should now work again.

### SSH problem for Ethernet connection
If the Pi and the PC are connected directly with an Ethernet cable, establishing the SSH connection may not work directly.
Follow the steps below to solve the problem:
- On the windows PC enable network sharing
  - Go to **Network connections** in the control panel.
  - If connected to the Internet through WiFi, right-click the Wi-Fi adapter and go to **Properties**
  - Go to **Sharing tab**
  - Enable **Allow other network users to connet through this computer's internet connection**
  - Choose the Ethernet adapter as the shared adapter. This will automatically assign the PC's ethernet and the Pi an IP in the same network.
- SSH into the Pi. The IP of the Pi can be found using **Advanced IP Scanner**. It should be something like **192.168.137.x**
    ```bash
    ssh <username>@<Pi_IP>
    ```
- If an error occurs like **Warning: Remote Host Identification has changed** and the connection is not established, this is due to the fact that the PC still has an old SSH fingerprint of the Pi stored (created by connecting wirelessly etc.). But now that the connection method has changed and that it has a new IP, the fingerprint doesn't match. To solve this issue, the old fingerprint needs to updated/removed:
  - In Windows Powershell
    ```bash
    ssh-keygen -R <Pi_IP>
    ```
  - SSH into the Pi
    ```bash
    ssh <username>@<Pi_IP>
    ```
  - If it asks **Are you sure you want to continue connecting (yes/no/[fingerprint])?**, say yes.
  - The SSH connection should now be established.

**Note:** If everything was configured correctly, the Ethernet cable connection should not only allow for SSH connection but also provides internet access to the RPi5 and allows a connection via NoMachine to visualize the running desktop environment.

## References
- Ubuntu Server Tutorial
https://ubuntu.com/tutorials/how-to-install-ubuntu-on-your-raspberry-pi#1-overview

- NoMachine Installation guide
https://kb.nomachine.com/DT04U00269#2.5

- NoMachine Download page for ARM
https://download.nomachine.com/download/?id=30&platform=linux&distro=arm

- NoMachine Download page for Windows:
https://download.nomachine.com/download/?id=3&platform=windows

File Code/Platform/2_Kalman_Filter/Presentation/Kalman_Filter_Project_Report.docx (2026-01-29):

Robotics Project Report

Jeremy Hendrikse & Julius Ortstadt

ROBO5

Table of Contents

Table of Figures

Appendices

## 1. Project Overview

This project proposed designing and implementing a Kalman filtering approach to a robot. In this case it was Grabby, an autonomous warehouse robot capable of autonomously mapping and navigating a warehouse like environment with the help of various actuators, sensors and algorithms.

To achieve this, it is equipped with a 2D LiDAR sensor, an Inertial Measurement Unit (IMU) and motor encoders. This non-exhaustive list doesn’t include all the necessary components but only those relevant to the scope of this project.

The mapping and navigation capabilities are obtained by using a ROS Navstack combined with AMCL (Advanced Monte Carlo Localization) and Google cartographer.

For the SLAM algorithm to localize the robot, it needs a pose estimation of the robot in its environment. It combines this first basic estimate with the LiDAR data to further enhance its positioning but also to acknowledge present obstacles and more. The Kalman filter that will be implemented in the scope of the project sits at the first step of the robots pose estimation. It will have access to the encoder data for each wheel as well as the IMU readings.


Figure 1 - Grabby

## 2. Robot Model

The warehouse robot Grabby used for this project is a differential-drive mobile robot. It is modeled as a rigid rectangular platform with two driven wheels and uniform mass distribution. Each wheel is controlled by a DC motor through a gearbox, and the robot moves by applying different voltages on the right and left motors.


Figure 2 - Robot representation

The main parameters of the robot are:

m=5 [kg] | Mass of the robot
L*l=0.49*0.33 [m] | Dimensions of the rectangular base
D=0.1m ⇒r=0.05 [m] | Wheel diameter and radius
L_w =0.2 [m] | Wheelbase (wheel separation)
N=98.78 | Gear ratio
J=0.145 [kg.m^2 ] | Moment of inertia of the robot
b=1.0 | Friction coefficient of the wheels
X_B -Y_B | Body frame
ψ [rad] | Heading of the robot (yaw angle)
ω=ψ [rad/s] | Angular velocity of the robot
V_B [m/s] | Linear velocity of the robot in the body frame
ϕ_l & ϕ_r [rad/s] | Angular velocity of the left and right wheels respectively
σ_v [m/s], σ_ψ [rad], σ_ψ [rad/s] | Standard deviations for the velocity (integrated from the accelerometer), yaw from the magnetometer and yaw rate from the gyrometer measurements respectively
q | Process noise scaling factor controlling the amount added to the model

To design the Kalman filter, a mathematical model of the robot is needed to rule the dynamics and kinematics of the filter. And based on the available sensors, the IMU readings will be used for the prediction step while the wheel encoders will serve as input to the system. This allows the system to have a greater robustness while limiting the effect of slip on the wheels and correcting the potential drift (and bias) of the encoder readings.

Since the filter’s goal is to provide a pose estimate of the robot, the corresponding state vector is defined as:

X=[, V_B , ψ, ψ]

The robot’s dynamics are described by a linearized dynamic model derived from the torque balance on each wheel using both forms of Newton’s second law:

{, mV_B =((τ_r)/r-bϕ_r )+((τ_l)/r-bϕ_l ), Jω=((τ_r)/r-bϕ_r )(L_w)/2-((τ_l)/r-bϕ_l )(L_w)/2

where τ_l & τ_r [N.m] is the torque exerted by the left and right wheel on the ground respectively.

The previous equations can be rewritten in matrix form:

[, V_B , ω]=[1/(mr), 1/(mr)(L_w)/(2rJ), -(L_w)/(2rJ)][, τ_r , τ_l ]+[-b/m, -b/m-(bL_w)/(2J), (bL_w)/(2J)][, ϕ_r , ϕ_l ]

The rotational velocity of the wheels is not directly used but rather the state vector and its components. Using the inverse kinematics, [, ϕ_r , ϕ_l ] can be substituted by X :

{, V_B +(L_w)/2 ψ= rϕ_r , V_B -(L_w)/2 ψ= rϕ_l ⇔{, ϕ_r =(V_B)/r+(L_w)/(2r)ψ, ϕ_l =(V_B)/r-(L_w)/(2r)ψ⇒[, ϕ_r , ϕ_l ]=[1/r, (L_w)/(2r)1/r, -(L_w)/(2r)][, V_B , ψ]

Therefore:

[-b/m, -b/m-(bL_w)/(2J), (bL_w)/(2J)][, ϕ_r , ϕ_l ]=[-b/m, -b/m-(bL_w)/(2J), (bL_w)/(2J)][1/r, (L_w)/(2r)1/r, -(L_w)/(2r)][, V_B , ψ]=[-(2b)/(mr), 00, -(bL_w ^2)/(2Jr)][, V_B , ψ]

It is now possible to write the continuous-time linear dynamics model of the system in the form X=FX+GU :

[, V_B , ψ, ψ]=[-(2b)/(mr), 0, 00, 0, 10, 0, -(bL_w ^2)/(2Jr)][, V_B , ψ, ψ]+[1/(mr), 1/(mr)0, 0(L_w)/(2Jr), -(L_w)/(2Jr)][τ_r τ_l ]

This continuous time state-space model is used to generate the simulation data and in the prediction step of the filter.

The matrices F and G are given by:

F=[-(2b)/(mr), 0, 00, 0, 10, 0, -(bL^2)/(2Jr)]] G=[1/(mr), 1/(mr)0, 0L/(2Jr), -L/(2Jr)]

This model accounts for the frictional losses in the wheels and the rotational coupling between the left and right torques.
For discrete-time simulation, the matrices were discretized using the sampling time T_s [s] :

Φ=I+FT_s and G_d =GT_s This representation allows the robot’s position, speed, and orientation (heading) to be estimated at each time step during simulation.

## 3. Kalman Filter Implementation

As previously explained, the objective of the Kalman Filter (KF) is to estimate the robot’s pose (speed, yaw, and yaw rate) from noisy sensor measurements. The simulation setup includes two types of sensor data:

- IMU: provides noisy measurements of the three states [v,ψ,ψ] where the speed v is obtained by integrating the acceleration measurement.
- Motor encoders: used indirectly to compute the estimated wheel torques applied to the robot through the motor equations.

### 3.1 Filter Initialization

The initial state estimate X_0 was set to zero, and the state-estimate error covariance matrix P_0 was initialized with large values ( 10^9 ) to represent complete uncertainty at the beginning.

P=[10^9 , 0, 00, 10^9 , 00, 0, 10^9 ] The process and measurement noise covariances were found to be:

Q=q×[T_s σ_v^2 , 0, 00, σ_ψ^2 ((T_s^3)/3), σ_ψ σ_ψ ((T_s^2)/2)0, σ_ψ σ_ψ ((T_s^2)/2), σ_ψ^2 T_s ] ; R=[σ_v^2 , 0, 00, σ_ψ^2 , 00, 0, σ_ψ^2 ]

These matrices were tuned empirically to achieve stable convergence and realistic noise behavior. The robot is currently undergoing design changes; this also concerns the sensors. Since these haven’t been chosen yet, typical values found through research were used to tune the noise parameters of the sensors in the simulation.

### 3.2 Filter Loop

At each iteration:

1. Update step: the filter corrects the predicted state using accelerometer data

K=PH^T (HPH^T +R)^(-1) X_(k∣k) =X_(k∣k-1) +K(Y_k -HX_(k∣k-1) ) P_(k∣k) =(I-KH)P_(k∣k-1)

2. Prediction step: the state is projected forward using the robot model and estimated torques

X_(k+1∣k) =ΦX_(k∣k) +G_d U_k P_(k+1∣k) =ΦP_(k∣k) Φ^T +Q

where H=[1, 0, 00, 1, 00, 0, 1]=I_3 since all three states are measured directly by the simulated IMU.

The filter therefore fuses sensor readings (accelerometer) and motor/encoder information (torque estimates) to produce a smooth, physically consistent estimate of the robot’s motion.

### 3.3 Simulation

To evaluate the filter in different motion conditions (straight line, rotation and variable speed), the simulation runs with different voltage profiles applied to the two motors:

- 12 V on both motors, reduced to 8 V on one side to simulate turning behavior.
- Later variations in voltage create curved trajectories and speed changes.

## 4. Results and Performance

The simulation first generates true states (velocity, yaw, yaw rate) using the robot model.
Noisy accelerometer and encoder signals are then created by adding Gaussian noise, simulating realistic sensors. It generates accurate data and can, if wanted, introduce bias or wheel slip in the simulation. This is the data that the KF will receive. A graphical representation of this procedure can be found in Appendix 1.

Note: The accelerometer data is integrated to get the values for the robot’s speed.


Figure 3 - Generated accelerometer data


Figure 4 - Generated motor data

Regarding the motor data, additional information on that topic can be found in Appendix 2.

The filter output X_(KF) closely follows the true robot state X_(truth) .
Plots of speed, yaw angle, and angular velocity show that:

- The estimated curves rapidly converge to the true values after a short transient phase. Something that is common in most types of filters.
- The noise in the accelerometer data is strongly reduced.
- The orientation estimate remains stable and smooth even when sensor noise increases.

By taking the given estimate and integrating the necessary components to obtain the robots position in a 2D plane, it can be observed that the robot trajectory also matches well with the ground truth path. Therefore, demonstrating that the KF provides reliable pose estimates for navigation and SLAM.

Moreover, by storing the square root of the covariance matrix P , the expected uncertainty bounds were plotted alongside the real estimation errors. All three state components remain within the expected error boundaries, confirming correct filter tuning and numerical stability.
The estimation errors for linear speed stay below ±0.02 m/s, and the yaw and yaw-rate errors remain minimal across the full simulation. Graphs showing the results are in Appendix 1.
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

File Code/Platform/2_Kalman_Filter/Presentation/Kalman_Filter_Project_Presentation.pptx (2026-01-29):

## Kalman Filtering approach for a differential drive robot Robotics Project

Jeremy Hendrikse & Julius Ortstadt
ROBO5

## Project overview and strategy

## Grabby: a warehouse robot

- Autonomous warehouse robot.
- Differential drive propulsion method.
- SLAM-based navigation.
- Major improvements from V2 to V4 (ROS version, modular building approach, better sensors).


Grabby V2

Grabby V4

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

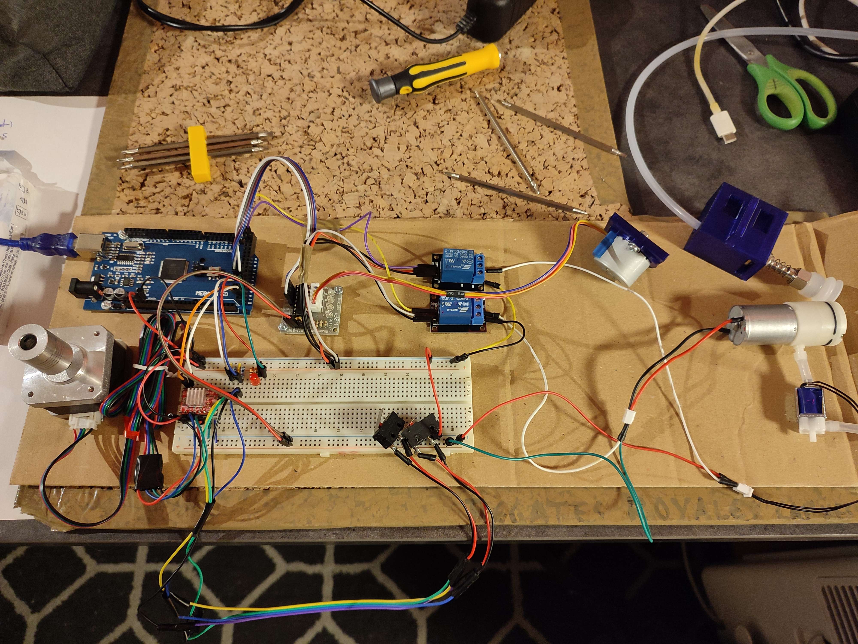
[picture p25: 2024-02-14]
Documentation/Robo3/Session_Reports/Jeremy/Pictures/CablageGrabbyV1.jpg

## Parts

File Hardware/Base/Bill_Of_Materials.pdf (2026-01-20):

Material | Quantity | Dimensions | Material | Status
Pillars | 4 See file | PETG Carbon
Basic adapter | 10 See file | PLA
Bi-face adapter | 14 See file | PLA
Bi-face adapter | 1 See file | PLA
Magnet adapter | 2 See file | PLA
Damper | 4 See file | Ninja FLEX
LiDAR Case | 1 See file | PLA
Interface simple (left) | 1 See file | PLA
Power interface (right) | 1 See file | PETG Carbon
Ball caster spacer | 4 See file | PETG Carbon
Centering bolt | 4 See file | PETG Carbon
BNO055 case | 1 See file | GreenTech Pro Carbon
RPi5 Assembly
Interface | 1 See file | PLA
Bottom | 1 See file | PLA
Power bloc
Base | 1 See file | PLA
Clamp | 1 See file | PLA
IMU case
Case | 1 See file | PLA
Clamp | 1 See file | PLA
Motor assembly
Bed | 1 See file | GreenTech Pro Carbon
Motor block | 1 See file | GreenTech Pro Carbon
Cover | 1 See file | PETG Carbon
Command deck | 1 See file | PETG Carbon
Back assembly
Box cover | 1 See file | PLA
Box | 1 See file | PLA
Vertical beams | 4 Length: 70mm | Alu 20x20
Long side beams | 4 Length: 330mm | Alu 20x20
Front, back, motor beams | 6 Length: 240mm | Alu 20x20
Front panel | 1 See DXF | CP 5mm
Right panel | 1 See DXF | CP 5mm
Left panel | 1 See DXF | CP 5mm
Back panel | 1 See DXF | CP 5mm
Top panel | 1 See DXF | CP 5mm
Front bottom top panel | 1 See DXF | CP 5mm
Front bottom bottom panel | 1 See DXF | CP 5mm
Back bottom top panel | 1 See DXF | CP 5mm
Back bottom bottom panel | 1 See DXF | CP 5mm

See "Panels.svg"

Print

Bill Of Materials (cut and print)

For cut sequence
see "Cut.txt"

Cut

Laser cut

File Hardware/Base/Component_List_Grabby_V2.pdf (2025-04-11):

Total

Component | Quantity | Price
Unit price | Sub-total
Ultrasonic sensor | 1 | 0,49 € | 0,49 €
Motors 99:1 | 2 | 55,90 € | 111,80 €
Motor support brackets | 2 | 9,10 € | 9,10 €
Motor Driver | 1 | 24,80 € | 24,80 €
Scooter Wheel | 2 | 3,70 € | 7,40 €
Wheel Hub | 2 | 6,80 € | 13,60 €
Ball caster wheel | 2 | 2,85 € | 5,70 €
Fuse 10A | 1 | 0,57 € | 0,57 €
Fuse 4A | 1 | 0,57 € | 0,57 €
Fuse holder | 1 | 0,49 € | 0,49 €
Inserts set | 1 | 5,80 € | 5,80 €
Connectors | 4 | 1,44 € | 1,44 €
Plastic Screw Waschers | 1 | 0,49 € | 0,49 €
DC-DC Converter | 1 | 3,00 € | 3,00 €
Nvidia Jetson Nano | 1 | 224,00 € | 224,00 €
Arduino Mega | 1 | 50,00 € | 50,00 €
Arduino Mega Shield | 1 | 4,17 € | 4,17 €
Cooling fan | 3 | 1,50 € | 4,50 €
12V Power Supply | 1 | 20,00 € | 20,00 €
Wood | 5 panels | 5,00 € | 25,00 €
PETG | 2kg | 30€/kg | 60,00 €
Cables | 1 | 17,00 € | 17,00 €
RPLiDAR A1 | 1 | 100,00 € | 100,00 €
MPU-6050 | 1 | 15,00 € | 15,00 €
MPU-9250 | 1 | 15,00 € | 15,00 €

719,92 €

Grabby - Component List

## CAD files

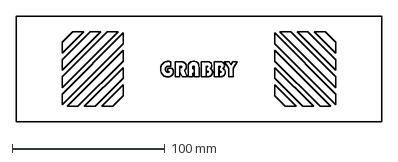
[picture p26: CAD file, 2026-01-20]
Hardware/Base/Panels/Front_panel.dxf
239.0 x 69.0 mm

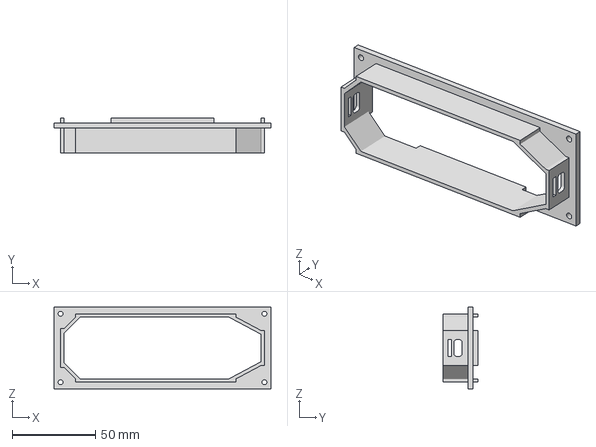
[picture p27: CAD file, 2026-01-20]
Hardware/Base/Prints/Back_assembly/Box.3mf
130.0 x 21.0 x 49.0 mm

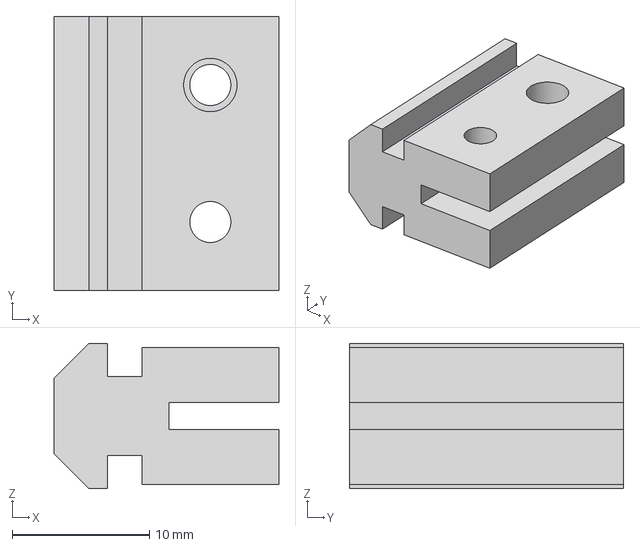
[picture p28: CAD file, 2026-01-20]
Hardware/Base/Prints/Bi_face_adapter.3mf
16.4 x 20.0 x 10.6 mm

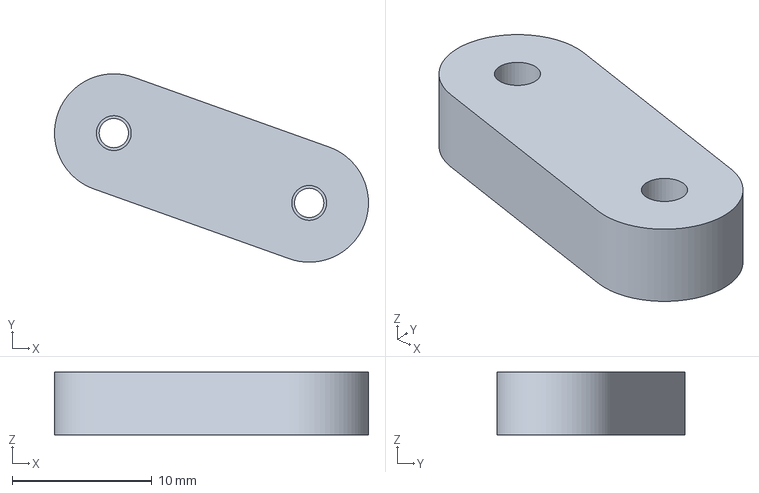
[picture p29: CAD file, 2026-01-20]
Hardware/Base/Prints/IMU_case/Clamp.3mf
22.5 x 13.5 x 4.51 mm

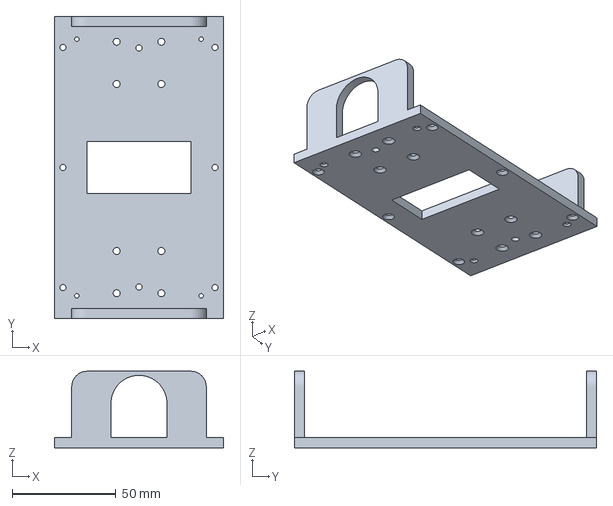
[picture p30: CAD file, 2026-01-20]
Hardware/Base/Prints/Motor_assembly/Motor_block.3mf
81.6 x 146.0 x 37.0 mm

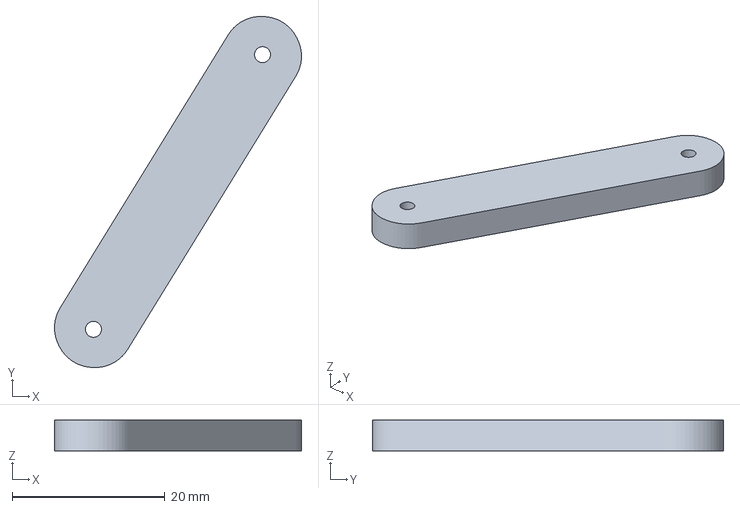
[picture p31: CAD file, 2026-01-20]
Hardware/Base/Prints/Power_bloc/Clamp.3mf
32.4 x 46.0 x 4.00 mm

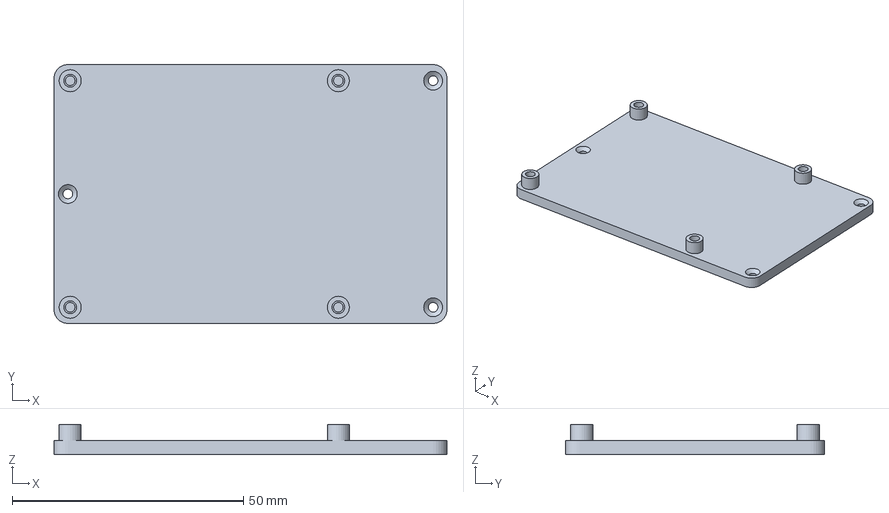
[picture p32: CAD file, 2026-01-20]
Hardware/Base/Prints/RPi5_assembly/Interface.3mf
85.0 x 56.0 x 6.52 mm

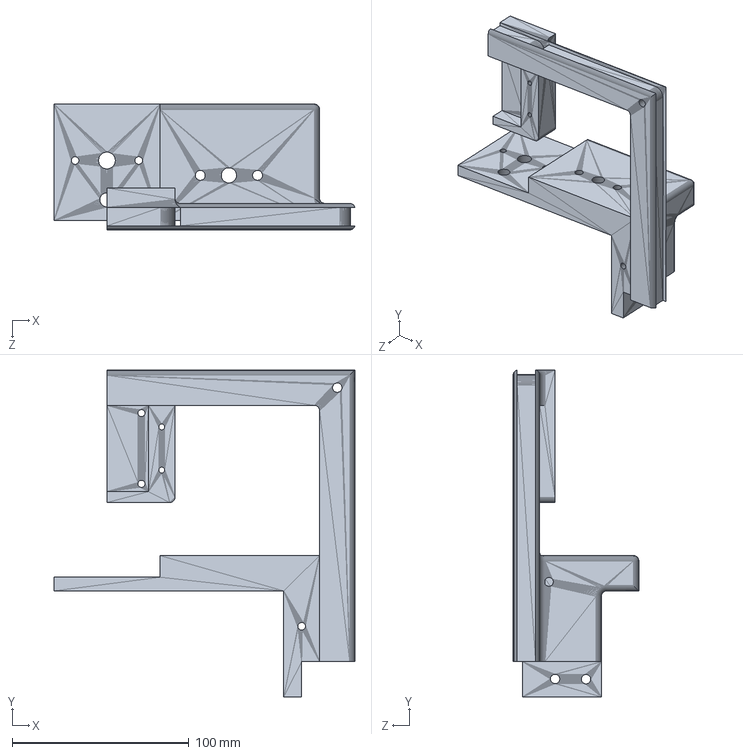
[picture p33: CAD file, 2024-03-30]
Hardware/LiftingPlatform/LowerPart/Frame/frame_back_right.SLDPRT
170.2 x 185.0 x 71.2 mm

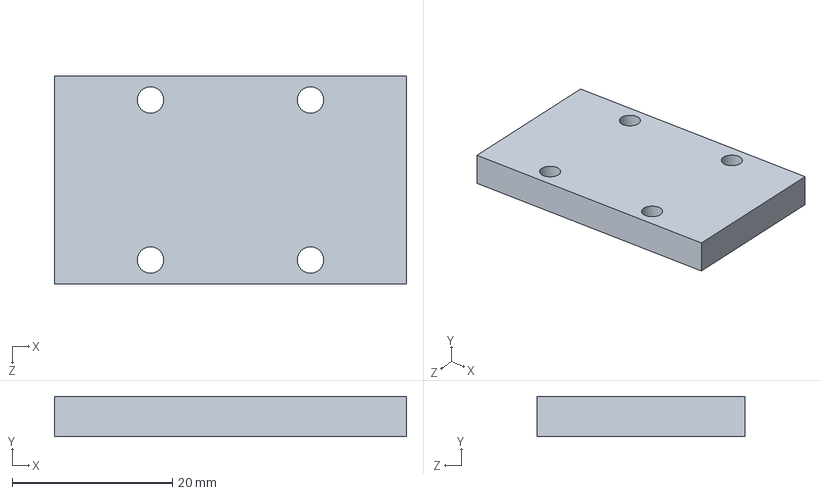
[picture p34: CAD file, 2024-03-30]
Hardware/LiftingPlatform/UpperPart/suction_cup_holder.SLDPRT
44.0 x 5.00 x 26.0 mm

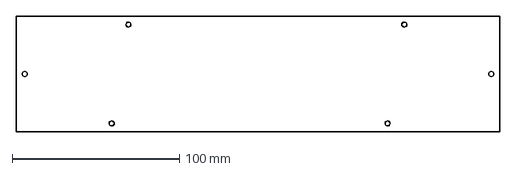
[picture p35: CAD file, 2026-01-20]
Hardware/Base/Panels/Left_panel.dxf
289.0 x 69.0 mm

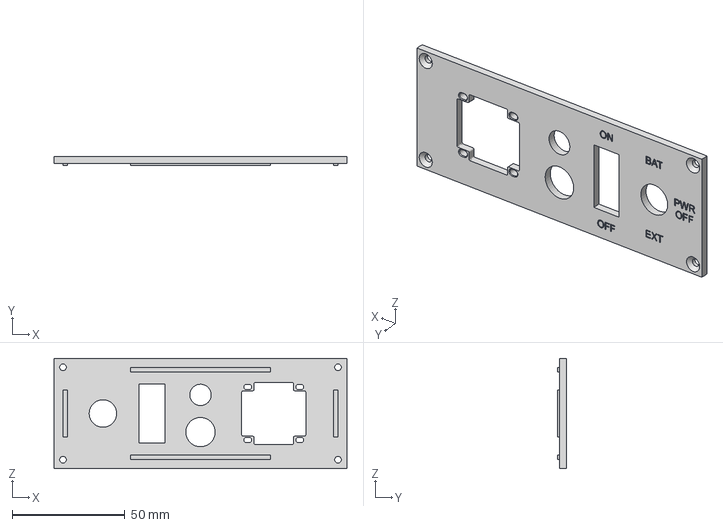
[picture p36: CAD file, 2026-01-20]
Hardware/Base/Prints/Back_assembly/Box_cover.3mf
130.0 x 4.00 x 49.0 mm

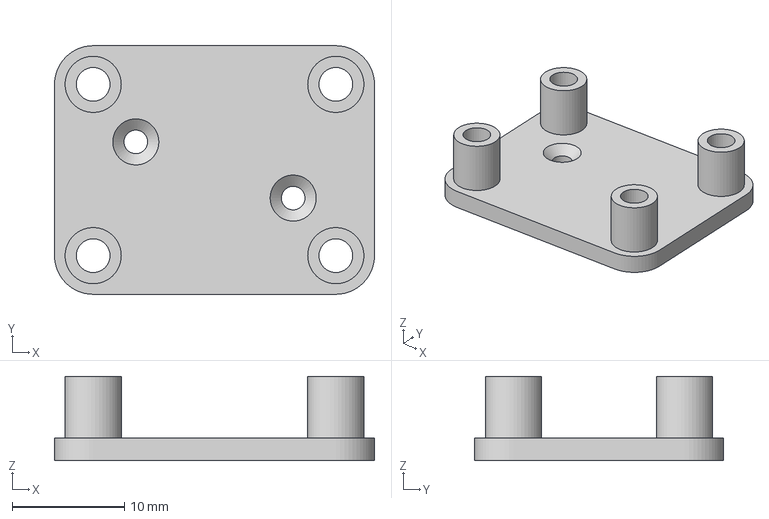
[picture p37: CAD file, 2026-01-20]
Hardware/Base/Prints/IMU_case/BNO055_Case.3mf
28.5 x 22.1 x 7.51 mm

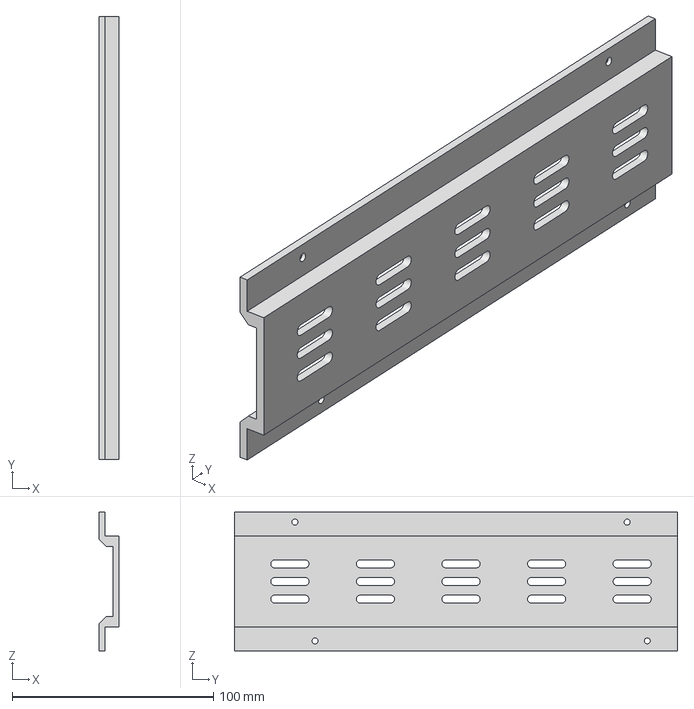
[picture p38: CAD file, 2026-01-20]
Hardware/Base/Prints/Interface_simple_left.3mf
10.0 x 220.0 x 69.0 mm

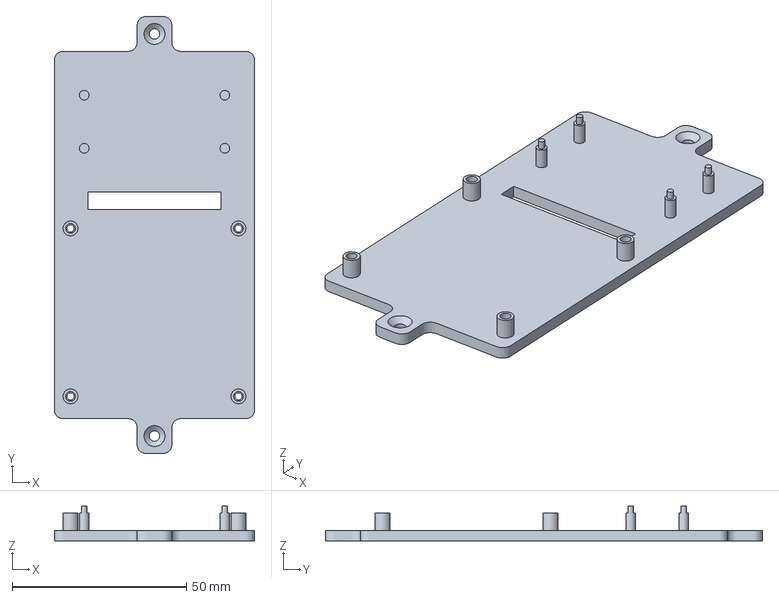
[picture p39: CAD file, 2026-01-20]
Hardware/Base/Prints/Motor_assembly/Command_deck.3mf
57.5 x 125.4 x 10.0 mm

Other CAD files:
Hardware/Base/Prints/Power_bloc/Base.3mf
Hardware/Base/Prints/RPi5_assembly/Bottom.3mf
Hardware/Base/Panels/Right_panel.dxf
Hardware/Base/Prints/Motor_assembly/Cover.3mf
Hardware/Base/Panels/Back_bottom_bottom_panel.dxf
Hardware/Base/Panels/Back_bottom_top_panel.dxf
Hardware/Base/Panels/Back_panel.dxf
Hardware/Base/Panels/Front_bottom_bottom_panel.dxf
Hardware/Base/Panels/Front_bottom_top_panel.dxf
Hardware/Base/Panels/Top_panel.dxf
Hardware/Base/Prints/Basic_adapter.3mf
Hardware/Base/Prints/Bolt.3mf
Hardware/Base/Prints/Damper.3mf
Hardware/Base/Prints/LiDAR_Case.3mf
Hardware/Base/Prints/Magnet_adapter.3mf
Hardware/Base/Prints/Motor_assembly/Bed.3mf
Hardware/Base/Prints/Pillar.3mf
Hardware/Base/Prints/Power_interface_right.3mf
Hardware/Base/Prints/Spacer.3mf

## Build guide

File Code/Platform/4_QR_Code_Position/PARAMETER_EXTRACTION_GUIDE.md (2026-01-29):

# Parameter Extraction Guide for 3D QR Code Positioning

## Overview

The `2_QR_code_position.py` script automatically extracts calibration parameters from the `.npz` file generated by the calibration script. If some parameters are missing, this guide explains how to obtain them.

## Parameters Extracted from NPZ File

### 1. **Camera Matrix (matrix_left, matrix_right)** ✓ Now Saved
- **What it is**: The intrinsic parameters of each camera (focal length, principal point)
- **Format**: 3x3 matrix
- **Contains**:
  ```
  [[fx  0  cx]
   [ 0 fy  cy]
   [ 0  0   1]]
  ```
  where:
  - `fx, fy`: focal length in pixels (horizontal and vertical)
  - `cx, cy`: principal point (image center) in pixels

### 2. **Baseline** ✓ Now Extracted
- **What it is**: Distance between the two camera centers
- **How it's extracted**: From the translation vector in the stereo calibration
  - `baseline = abs(translation_vector[0][0])`
  - This assumes stereo cameras are arranged horizontally (most common setup)
- **Units**: Millimeters (if calibration was done in mm)

### 3. **Focal Length** ✓ Extracted from Camera Matrix
```python
f = (camera_matrix[0, 0] + camera_matrix[1, 1]) / 2
```

### 4. **Principal Point** ✓ Extracted from Camera Matrix
```python
cx = camera_matrix[0, 2]
cy = camera_matrix[1, 2]
```

## Updated Calibration Script

The calibration script `2_get_camera_parameters.py` has been updated to save:
- ✓ `matrix_left` and `matrix_right`
- ✓ `translation_vector` (used to calculate baseline)
- ✓ `leftProjection` and `rightProjection`
- ✓ All previous parameters (leftMapX, leftMapY, etc.)

**To apply these changes**: Run the calibration script again:
```bash
cd ../Calibration
python 2_get_camera_parameters.py
```

This will overwrite the previous `.npz` file with all the new parameters.

## What If Parameters Are Still Missing?

If you have an older `.npz` file that doesn't contain the new parameters:

### Option 1: Manual Calibration Values
Edit the extraction code in `2_QR_code_position.py` to use manual values:

```python
# Manually set if not found in file
if matrix_left is None:
    # Create a basic camera matrix if needed
    # Format: [[fx, 0, cx], [0, fy, cy], [0, 0, 1]]
    focal_length = 500  # pixels (adjust based on your camera)
    matrix_left = np.array([
        [focal_length, 0, 640],  # assuming 1280 width
        [0, focal_length, 360],   # assuming 720 height
        [0, 0, 1]
    ])

if baseline is None:
    baseline = 60  # mm (distance between cameras)
```

### Option 2: Extract from Your Specific Camera
If you know your camera model:

1. **For USB Stereo Cameras**: Check the manufacturer's specification sheet
2. **For OpenCV calibration**: The values are calculated during `cv.calibrateCamera()` and `cv.stereoCalibrate()`

### Option 3: Measure Physically
- **Baseline**: Measure the distance between the two camera centers with a ruler (in mm)
- **Focal length**: 
  - Requires detailed camera specifications
  - Or calculated from calibration: `focal_length = known_distance * pixels_in_image / actual_object_size`

## How the 3D Position is Calculated

Once parameters are extracted, the 3D position is calculated as:

```
disparity = x_left - x_right  (in pixels)
Z = (f * baseline) / disparity  (depth, in same units as baseline)
X = (x_left - cx) * Z / f  (horizontal offset)
Y = (y_left - cy) * Z / f  (vertical offset)
```

**Coordinate System Origin**: Left camera's optical center
- **X-axis**: pointing right
- **Y-axis**: pointing down
- **Z-axis**: pointing forward into the scene

## Current Flow in 2_QR_code_position.py

1. **Load calibration file** with `allow_pickle=True`
2. **Extract camera matrices** and compute focal length + principal point
3. **Extract baseline** from translation vector
4. **When matching QR found**: Calculate 3D position using `triangulate_qr_position()`
5. **Display results** with all 3D coordinates

## New Looping Behavior

- **Press 's'**: Start QR code detection loop
- **Loop continues** until a matching QR code is found in both left and right frames
- **When found**: Display 3D position and **stop looping**
- **Press 's' again**: Restart detection for another QR code
- **Press 'e'**: Exit program

## Troubleshooting

| Issue | Solution |
|---|---|
| "Missing calibration data" warning | Re-run `2_get_camera_parameters.py` to save the new parameters |
| 3D coordinates are unrealistic (too far/close) | Adjust `baseline` value - it's likely incorrect |
| Positions are off by scale factor | Ensure baseline units match (should be mm) |
| No disparity calculated | QR code might not be visible in both frames |

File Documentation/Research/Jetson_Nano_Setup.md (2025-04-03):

# Jetson Nano - LiDAR Work Documentation
#### Author: Julius Ortstadt

## Note
The information about how to write the code for the autonomous robot is presented in part in this document but also in the relevant part of the code section.\
For the mapping process, a different algorithm has been used as described here.\
This file should be use to setup the jetson itself and the dependencies and not for coding the actual robots actions.

## Introduction
This document will show step-by-step how I prepared the NVIDIA Jetson Nano for different tasks for the Grabby Warehouse robot project.

It is supposed that the Jetson Nano already has an OS installed and was setup. This document only shows different parts which group different tutorials found online.

## Remote desktop using NoMachine
In order to remotely connect the Nano with my PC so that I could see the desktop without any wired connection to another monitor I followed the tutorial made by [JetsonHacks](https://jetsonhacks.com/2023/12/03/nomachine-jetson-remote-desktop/).

Here are some [NoMachine installation tips](https://kb.nomachine.com/AR02R01074).

*Note*:
During the installation, you will be asked to [disable the xserver](https://forums.developer.nvidia.com/t/easy-way-to-change-a-default-nano-setup-to-work-in-headless-mode-ie-no-gui-services/107268). 
There are two ways to do it:
- Permantly
```
sudo systemctl set-default multi-user.target
```
- Temporarily
```
sudo systemctl isolate multi-user.target
```

If you chose the temporarily option, you will need to run the command everytime the Jetson is rebooted.
You then need to run this command (also everytime if you choose the temporarily option) which will restart the nxserver:
```
sudo /usr/NX/bin/nxserver --restart
```

However if you want to go back and un-disable the xserver, run the following command:
```
sudo systemctl set-default graphical.target
```

I also decided to [install JTOP](https://jetsonhacks.com/2023/02/07/jtop-the-ultimate-tool-for-monitoring-nvidia-jetson-devices/) in order to monitor the Jetsons performance.

*Important information*\
I haven't been to change the keyboard layout on the Jetson Nano. 
Therefore, I need to write the text in need on my computer and then copy/paste.

## ROS Melodic installation
For the ROS installation I followed a great tutorial made by [AutomaticAddison](https://automaticaddison.com/how-to-install-ros-melodic-on-the-nvidia-jetson-nano/) which I found on the [NVIDIA Developper Forum](https://forums.developer.nvidia.com/t/autonomous-mobile-robot-navigation-with-ros-jetson-nano-arduino-lidar-extended-kalman-filter/189802).

Here is also the link to the [official ROS wiki installation tutorial](http://wiki.ros.org/melodic/Installation/Ubuntu).

Additional information on how to source a [ROS Project](http://wiki.ros.org/ROS/Tutorials/InstallingandConfiguringROSEnvironment):
```
$ source /opt/ros/melodic/setup.bash
```
    
## First LiDAR Test
Now that we installed ROS on the Jetson. 
Let's setup our LiDAR so that we can see everything on the desktop.

I will base this work on the following tutorial:\
[*How to Build an Indoor Map Using ROS and LIDAR-based SLAM*](https://automaticaddison.com/how-to-build-an-indoor-map-using-ros-and-lidar-based-slam/#Connect_Your_RPLIDAR)

### Connect the LiDAR
1. Connect the LiDAR to the USB
2. Run: 
```
ls -l /dev | grep ttyUSB
```
3. Change the permission:
```
sudo chmod 666 /dev/ttyUSB0
```

### Create a catkin workspace and visualize the LiDAR data in the terminal
1. Update the Jetson
```
sudo apt-get update
```
2. Install the dependencies
```
sudo apt-get install cmake python-catkin-pkg python-empy python-nose python-setuptools libgtest-dev python-rosinstall python-rosinstall-generator python-wstool build-essential git
```

3. Create the [catkin workspace](http://wiki.ros.org/catkin/Tutorials/create_a_workspace). 
I chose to do it in a folder name "LiDAR_Test".
```
mkdir -p ~/LiDAR_Test/catkin_ws/src
```
```
cd ~/LiDAR_Test/catkin_ws/
```

4. Let's modify the .bash file so that we don't have to source the setup.bash file every time we open a new linux terminal.
Open a new terminal and type:
```
nano ~/.bashrc
```

5.  Verify that these two lines are at the end of the file:
```
source /opt/ros/melodic/setup.bash
source ~/LiDAR_Test/catkin_ws/devel/setup.bash
```

6. Type the following command to source the file:
```
source ~/LiDAR_Test/catkin_ws/devel/setup.bash
```
7. Go back to the src folder and clone the RPLIDAR ROS package to this folder:
```
sudo git clone https://github.com/Slamtec/rplidar_ros.git
```
8. Go to the root of the workspace and compile it:
```
catkin_make
```

9. Source the file:
```
source ~/LiDAR_Test/catkin_ws/devel/setup.bash
```

10. In another terminal window launch the Roscore
```
roscore
```
11. In the window where we have our catkin_ws, launch the package (I am working with the A1 lidar, so the command that I need to use is the one below. If you use another LiDAR you need to check the README.md file in the git repo of the RPLIDAR)
```
roslaunch rplidar_ros rplidar_a1.launch
```
12. If everything was successful, let's see our active topics:
```
rostopic list
``` 

13. We should see a */scan* topic. 
If this is the case, everything went fine. 
Type the following to see the raw LiDAR data in the terminal:
```
rostopic echo /scan
```

### Visualize the data with rviz
In order to do this we need to connect to the Jetson via NoMachine which we setup earlier. 
Do all the step until you are on the desktop of the LiDAR.
You need to have launched the package like we did before for these steps.

1. Open a new terminal window and launch rviz
```
rviz
```

2. In *Global Options* change the **Fixed Frame** to **laser**

3. Click the **Add** button.

4. Select **LaserScan** and click **OK**

5. Set the **LaserScan** topic to **/scan**

6. Increase the size to **0,03** (for better visibility)

If you see everything correctly that means that everything is working great.

### Build a map using the Hector-SLAM ROS package
Now we want to build a map using our LiDAR. To do this we need to setup hector_slam for our robot.\
[Here is the link to the official ROS wiki for hecto_slam](http://wiki.ros.org/hector_slam/Tutorials/SettingUpForYourRobot)

One important thing before we start this process. 
Since I work through Wi-Fi, the quality of the NoMachine stream is not the best.
I therefore connect with NoMachine only for the rviz part.
For the rest I just open multiple windows terminals in which I connect via ssh and execute the commands.
Here is how I structure it:
- One ssh terminal with roscore
- One ssh terminal where I will launch the launch file
- One ssh terminal where I usually setup headless mode, set the rights for the usb ...
- One connection via NoMachine to connect to the desktop where I launch rviz.
    
#### Install Qt4
Qt4 is a software that is used to generate graphical user interfaces.
```
sudo apt-get install qt4-qmake qt4-dev-tools
```
#### Download Hector-SLAM
1. Go to the catkin workspace's source folder
```
cd ~/LiDAR_Test/catkin_ws/src
```

2. Now we clone the git:
```
git clone https://github.com/tu-darmstadt-ros-pkg/hector_slam.git
```
#### Set the coordinate frame parameters
We now need to set the frame names and options correctly. 
For more information about Coordinate Frames see the blog post by [AutomaticAddison](https://automaticaddison.com/coordinate-frames-and-transforms-for-ros-based-mobile-robots/) and the [official ROS wiki](http://wiki.ros.org/hector_slam/Tutorials/SettingUpForYourRobot).

To do this follow the steps below:
1. Go to the launch file for Hector-SLAM:
```
sudo gedit ~/catkin_ws/src/hector_slam/hector_mapping/launch/mapping_default.launch
```

2. Look for the following lines:
```
<arg name="base_frame" default="base_footprint"/>
<arg name="odom_frame" default="nav"/>
```
And change them to this:
```
<arg name="base_frame" default="base_link"/>
<arg name="odom_frame" default="base_link"/>
```

3. Do the same thing with the following. Change this:
```
<!--<node pkg="tf" type="static_transform_publisher" name="map_nav_broadcaster" args="0 0 0 0 0 0 map nav 100"/>-->
```
to this
```
<node pkg="tf" type="static_transform_publisher" name="base_to_laser_broadcaster" args="0 0 0 0 0 0 base_link laser 100"/>
```

4. Save the file and return.
5. Go here:
```
cd ~/LiDAR_Test/catkin_ws/src/hector_slam/hector_slam_launch/launch
```

6. Open the tutorial.launch file. I will be using nano for the editor.
```
nano tutorial.launch
```

7. Find the following line:
```
<param name="/use_sim_time" value="true"/>
```
and change it to this:
```
<param name="/use_sim_time" value="false"/>
```

8. Save and return.
9. Build the packages with **catkin_make** when you are in **~/LiDAR_Test/catkin_ws/**

In my case I had an error making it impossible for the **catkin_make** to work.
The error was *Project ‘cv_bridge’ specifies ‘/usr/include/opencv’ as an include dir, which is not found. It does neither exist as an absolute directory nor in…*.
I found a fix that worked for me:
```
cd /usr/include
```
```
sudo ln -s opencv4/ opencv
```
After doing this, try building the packages again.
Normally it should work now.

If you want you can do a reboot of the Jetson.

#### Launch the mapping process
Since we did a reboot of the Jetson we need to [set it up for headless mode again](#remote-desktop-using-nomachine) (if you chose the temporary method).

Now let's launch the RPLIDAR.
It's important to note that you need to have roscore launched in another terminal window.

Type the following commands:
```
cd ~/LiDAR_Test/catkin_ws/
```
```
sudo chmod 666 /dev/ttyUSB0
```
```
roslaunch rplidar_ros rplidar_a1.launch
```

On the desktop of the Jetson, open a new terminal and type the following command. 
This will start the mapping process as well as starting rviz.
```
roslaunch hector_slam_launch tutorial.launch
```

In order for the mapping to work correctly, you need to move the LiDAR slowly across the room.

#### Save the map
There are multiple ways to save a map.
Here is the first one:
1. In the terminal (in my case one via ssh) type the following:
```
rostopic pub syscommand std_msgs/String "savegeotiff"
```

2. When the mapping is done, hit CTRL+C

3. You can find your map in *~/LiDAR_Test/catkin_ws/src/hector_slam/hector_geotiff/maps*

## Connect Arduino and Jetson
The next step for this project is to connect the Arduino with the Jetson.

### Download, install and setup the IDE
Since we are on the Jetson we can simply use a terminal.

```
git clone https://github.com/JetsonHacksNano/installArduinoIDE.git
```
```
cd installArduinoIDE
```
```
./installArduinoIDE.sh
```

This is an older version of the IDE but it still works very well.

Reboot the jetson with **sudo reboot**.
You will now see a desktop shortcut for the IDE. 
(I had to click on it and say that I trust it.)

Now shut everything down and plug the Arduino into one of the USB ports.
Boot everything up again.
When in the IDE select the board and the poart that you are using.
If you're not sure about the port, open a new terminal and type the following:
```
ls -l /dev | grep ttyUSB
```
This will show you all the devices connected via USB and therefore the port.
Select the right one in the IDE and you're ready to go.
I used an **Arduino Mega 2560** on port **/dev/ttyUSB0**

*Test:*
Go to **File -> Examples -> 01.Basics -> Blink**.
When you upload this code, the LED on the Arduino should blink if everything was done right.

### Integrate Arduino with ROS
The official guide can be found [here](http://wiki.ros.org/rosserial_arduino/Tutorials/Arduino%20IDE%20Setup).

Here is what I did:
1. Open a new terminal and install the following things:
```
sudo apt-get install ros-melodic-rosserial-arduino
```
```
sudo apt-get install ros-melodic-rosserial
```

2. Note the location of the sketbook. (**File -> Preferences**).
3. Close the IDE and go to the sketchbook location through a terminal.
4. Go to the *libraries* directory and type the following:
```
rm -rf ros_lib
```
5. Still in this directory:
**(With the period at the end)**
```
rosrun rosserial_arduino make_libraries.py .
```
6. With **dir** you should now see the *ros_lib* folder.

You can now experiment with some examples from this library.
Some more explanation can be found in the *Integrate Arduino With ROS * section of [this](https://automaticaddison.com/how-to-publish-wheel-encoder-tick-data-using-ros-and-arduino/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) tutorial.

## Create the launch file for the project
In this part I will start creating the launch file for the entire project.

This will take bits of different sections of this doc. 

Let's start:
1. Create a location for the project:
```
mkdir -p ~/Grabby/catkin_ws/src
```
2. Go to this location and make the project:
```
cd Grabby/catkin_ws/
```
```
catkin_make
```
3. Create a folder in the *src* folder:
```
cd src
```
```
mkdir grabby
```
4. Move to the newly created folder and create the package:
```
catkin_create_pkg launch_grabby rospy roscpp std_msgs sensor_msgs geometry_msgs tf
```
5. Go to launch_grabby
6. Create a new folder. 
I will name it *launch*
7. Go to the main folder of the catkin workspace:
```
cd ~/Grabby/catkin_ws
```
8. Compile the package
```
catkin_make --only-pkg-with-deps launch_grabby
```
9. Source the catkin workspace.
```
source ~/Grabby/catkin_ws/devel/setup.bash
```
10. Mode inside the package
```
roscd launch_grabby
```
11. Edit the CMakeLists.txt file.
```
nano CMakeLists.txt
```
12. Remove the "#" on line 5 to enable C++11 support.
Then save and close.
13. Go to the launch folder and create a new launch file.
This is the file that will hold all the information about nodes etc. for the entire project.
```
cd launch
```
```
nano grabby.launch
```

### Add the Arduino Node to the launch file
Here we are going to add the node for Arduino to our launch file.
1. Add the following to the file (some things may vary depending on how everything is setup):
```
<launch>
  <node pkg="rosserial_python" type="serial_node.py" name="serial_node">
    <param name="port" value="/dev/ttyUSB0"/>
    <param name="baud" value="115200"/>
  </node>
</launch>
```
2. Save, close and change the permissions.
```
sudo chmod +x grabby.launch
```
3. Open a new terminal and launch the file.\
*Note: Roscore must be active in another terminal.*
```
roslaunch launch_grabby grabby.launch
```
4. When you type **rostopic list** in another terminal, you should be able to see your active topics, as well as access the data being published.

### Add the LiDAR Node to the launch file
In this part we will publish the LiDAR data. 
I used [this tutorial](https://automaticaddison.com/how-to-publish-lidar-data-using-a-ros-launch-file/).
1. Get the port of the LiDAR and change its permissions.
2. Go to the *src* folder of our workspace and clone the following git:
```
sudo git clone https://github.com/Slamtec/rplidar_ros.git
```
3. Go to the root of the workspace and do **catkin_make**

**Note**
If you haven't added the launch file to the .bashrc file, do it now so that you don't have to source it everytime:
```
cd ~
```
```
nano /.bashrc
```
Add the following lines:
```
source /opt/ros/melodic/setup.bash
source ~/Grabby/catkin_ws/devel/setup.bash
```
4. Go to the where our launch file is located. 
In this case:
```
cd ~/Grabby/catkin_ws/src/grabby/launch_grabby/launch
```
5. We need to install the ros package for the LiDAR.
Go to the root of the workspace.
```
catkin_make --only-pkg-with-deps rplidar_ros
```
6. In the launch file, add the following:
```
<!-- Lidar Data Publisher using the RPLIDAR A1 from Slamtec -->
<!-- Used for mapping and obstacle avoidance -->
<!-- Publish: /scan -->
<node pkg="rplidar_ros" type="rplidarNode" name="rplidarNode" output="screen">
  <param name="serial_port" value="/dev/ttyUSB0" type="string"/>
  <!-- For RPLIDAR A1 Baudrate is 115200 -->
  <param name="serial_baudrate" value="115200" type="int"/>
  <param name="frame_id" value="laser" type="string"/>
  <param name="inverted" value="false" type="bool"/>
  <param name="angle_compensate" value="true" type="bool"/>
</node>  
```

7. In another terminal, run **roscore**
8. In the other terminal, we will now launch our file:
```
roslaunch launch_grabby grabby.launch
```
9. In this case, there will be interference with the part of the file for the Arduino.
Just comment it.
We'll get back to this later.
10. Launch the file.
Type **rostopic list**. 
You should now see the */scan* topic. 
If you type *rostopic echo /scan* you will see the data being published.
11. If you want to visualize the data via rviz, you can do the steps in this [section](#visualize-the-data-with-rviz).
Just run **rosrun rviz rviz** in the terminal.

### How to Control a Robot’s Velocity Remotely Using ROS
I followed [this tutorial](https://automaticaddison.com/how-to-control-a-robots-velocity-remotely-using-ros/).

The code can be found in this github.
I is called "jetson_motor_control.ino".
You may need to adjust some of the values depending on the specs of the robot.
We will use **rqt** to drive the robot.

1. Start a **roscore** in a terminal.
2. Run the following command in another one to start the serail node between the Jetson and the Arduino:
```
rosrun rosserial_python serial_node.py _port:=/dev/ttyUSB0 _baud:=115200
```
The value of the port may need to be changed according to the wiring of the robot.

3. In another terminal run this:
```
rosrun rqt_robot_steering rqt_robot_steering
```
4. You should now see data being published onto the **/cmd_vel** topic when you change the values on the slider.

**Note:**\
You can add this to the main launch file.
Just add the following to the launch file:
```
<node pkg="rqt_robot_steering" type="rqt_robot_steering" name="rqt_robot_steering">
</node>
```

### How to Create an Initial Pose and Goal Publisher in ROS
I followed [this tutorial](https://automaticaddison.com/how-to-create-an-initial-pose-and-goal-publisher-in-ros/).

Here is a quick guide:
1. First we need to create a package:
```
cd ~/Grabby/catkin_ws/src/grabby/
```
```
catkin_create_pkg localization_data_pub rospy roscpp std_msgs tf tf2_ros geometry_msgs sensor_msgs nav_msgs
```
2. Let's compile the package:
```
cd ~/Grabby/catkin_ws/

catkin_make --only-pkg-with-deps localization_data_pub 
```
3. Go inside the package and enable C++11 support (remove "#" on line 5).
```
cd ~/Grabby/catkin_ws/src/grabby/localization_data_pub/

nano CMakeLists.txt
```
4. For more information as to why we need to create a code which converts inputs from rviz to a different format take a look at the tutorial linked above.
5. Put the code named "rviz_click_to_2d.cpp" from this github into a file with the same name at this location:
**cd ~/Grabby/catkin_ws/src/grabby/localization_data_pub/src**
6. Type: **cd ..** to go back one folder. 
When there, add the following to the CMakeLists.txt file:
```
INCLUDE_DIRECTORIES(/usr/local/lib)
LINK_DIRECTORIES(/usr/local/lib)
 
add_executable(rviz_click_to_2d src/rviz_click_to_2d.cpp)
target_link_libraries(rviz_click_to_2d ${catkin_LIBRARIES})
```
7. Compile the code:
```
cd ~/Grabby/catkin_ws

catkin_make --only-pkg-with-deps localization_data_pub
```
8. Let's try the code (in different terminals):
```
roscore
```
```
rosrun localization_data_pub rviz_click_to_2d
```
```
rviz
```
```
rostopic echo /initial_2d
```
```
rostopic echo /goal_2d
```
9. In rviz, when you click the 2D Pose Estimate button, click on the map and do the same with the 2D Nav Goal, you should see something in the two topics that are echoed in the terminal.

**Note:**\
We can add this to the main launch file.
```
<!-- Initial Pose and Goal Publisher -->
<!-- Publish: /initialpose, /move_base_simple/goal -->
<node pkg="rviz" type="rviz" name="rviz">
</node>
<!-- Subscribe: /initialpose, /move_base_simple/goal -->
<!-- Publish: /initial_2d, /goal_2d -->
<node pkg="localization_data_pub" type="rviz_click_to_2d" name="rviz_click_to_2d">
</node>   
```

### How to Publish Wheel Odometry Information Over ROS
I followed [this tutorial](https://automaticaddison.com/how-to-publish-wheel-odometry-information-over-ros/).

Here is a quick guide (for more details, see the tutorial linked above):
1. Go to the source folder of our localization package and create a new C++ file:
```
cd ~/Grabby/catkin_ws/src/grabby/localization_data_pub/src

nano ekf_odom_pub.cpp
```
2. Into this file, put the code named *ekf_odom_pub.cpp* from this github repo.
3. Add the programm to the CMakeLists.txt file:
```
cd ~/Grabby/catkin_ws/src/grabby/localization_data_pub/

nano CMakeLists.txt
```
4. Add the following to this file:
```	
add_executable(ekf_odom_pub src/ekf_odom_pub.cpp)
target_link_libraries(ekf_odom_pub ${catkin_LIBRARIES})
```
5. Compile the workspace:
```
cd ~/catkin_ws

catkin_make --only-pkg-with-deps localization_data_pub
```
6. Let's test it out:
  - Start ros with **roscore**
  - Launch the node in another terminal
  ```
  rosrun localization_data_pub ekf_odom_pub
  ```
  - Start the tick counter publisher by connecting to the arduino. The code "jetson_motor_control.ino" should still be uploaded on the arduino. **Note: Change the port if necessary.**
  ```
  rosrun rosserial_python serial_node.py _port:=/dev/ttyUSB0 _baud:=115200
  ```
  - In another terminal launch the initial pose and goal publisher:
  ```
  rosrun localization_data_pub rviz_click_to_2d
  ```
  - Start rviz
  - If you set the initial pose and the nav goal with rviz you should see something being published in */odom_data_quat*.

**Note:**\
You can add this to the main launch file:
```
<!-- Wheel Odometry Publisher -->
<!-- Subscribe: /right_ticks, /left_ticks, /initial_2d -->
<!-- Publish: /odom_data_euler, /odom_data_quat -->
<node pkg="localization_data_pub" type="ekf_odom_pub" name="ekf_odom_pub">
</node> 
```

## Other links
- Setup and Configuration of the Navigation Stack on a Robot
http://wiki.ros.org/navigation/Tutorials/RobotSetup

- How to Create and Execute ROS Launch Files
https://automaticaddison.com/how-to-create-and-execute-ros-launch-files/

The next steps are in this order:
- How to Create and Execute ROS Launch Files
https://automaticaddison.com/how-to-create-and-execute-ros-launch-files/

- Next is Coordinate Frames and Transforms for ROS-based Mobile Robots
https://automaticaddison.com/coordinate-frames-and-transforms-for-ros-based-mobile-robots/
Make the robot use TF: http://wiki.ros.org/navigation/Tutorials/RobotSetup/TF

- Publishing Sensor Streams Over ROS (LaserScans or PointClouds):
http://wiki.ros.org/navigation/Tutorials/RobotSetup/Sensors

- 3D rotation matrix with python code:\
https://automaticaddison.com/how-to-describe-the-rotation-of-a-robot-in-3d/

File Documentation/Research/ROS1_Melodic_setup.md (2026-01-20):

# Setup of the RPi5 with ROS1 Melodic for the Grabby Project

---

**Project:** Grabby\
**Author:** Julius Ortstadt\
**Date:** 03.12.2025\
**Description:** This is a continuation of the practical guide on how to set up the RaspberryPi 5 for the Grabby project. This tutorial covers the topics on installing and setting up ROS1 Melodic for the project.

---

## Table of contents
- [Setup of the RPi5 with ROS1 Melodic for the Grabby Project](#setup-of-the-rpi5-with-ros1-melodic-for-the-grabby-project)
  - [Table of contents](#table-of-contents)
  - [Prerequisites](#prerequisites)
  - [Login credentials](#login-credentials)
  - [Install Docker](#install-docker)
  - [Pull the Docker image](#pull-the-docker-image)
  - [Run the Docker container](#run-the-docker-container)
    - [Start command](#start-command)
    - [Control a Docker container](#control-a-docker-container)
    - [Docker ROS Melodic Container Command Breakdown](#docker-ros-melodic-container-command-breakdown)
  - [Arduino ROS library files](#arduino-ros-library-files)
    - [Additional configuration](#additional-configuration)
      - [.bashrc](#bashrc)
      - [Make bash shell sudo](#make-bash-shell-sudo)
      - [Install additional packages](#install-additional-packages)
  - [Troubleshooting](#troubleshooting)
    - [CMake version out-of-date](#cmake-version-out-of-date)
  - [References](#references)

## Prerequisites
The **Pi5_set_up_Ubuntu** guide needs to be completed before the tasks presented in this guide. 

## Login credentials
**Device name:** rpi\
**Username:** rpi\
**Password:** rpi 

## Install Docker
To install Docker, execute the following steps which can also be found [here](https://docs.docker.com/engine/install/ubuntu/):
- Set up Docker's **apt** repository:
```bash
# Add Docker's official GPG key:
sudo apt update
sudo apt install ca-certificates curl
sudo install -m 0755 -d /etc/apt/keyrings
sudo curl -fsSL https://download.docker.com/linux/ubuntu/gpg -o /etc/apt/keyrings/docker.asc
sudo chmod a+r /etc/apt/keyrings/docker.asc

# Add the repository to Apt sources:
sudo tee /etc/apt/sources.list.d/docker.sources <<EOF
Types: deb
URIs: https://download.docker.com/linux/ubuntu
Suites: $(. /etc/os-release && echo "${UBUNTU_CODENAME:-$VERSION_CODENAME}")
Components: stable
Signed-By: /etc/apt/keyrings/docker.asc
EOF

sudo apt update
```

- Install the Docker packages
```bash
sudo apt install docker-ce docker-ce-cli containerd.io docker-buildx-plugin docker-compose-plugin
```

- Verify that Docker is running or start it
```bash
sudo systemctl status docker

sudo systemctl start docker
```

- Verify the installation by running the **hello-world** image:
```bash
sudo docker run hello-world
```
This command downloads a test image and runs it in a container. When the container runs, it prints a confirmation message and exits.

## Pull the Docker image
There is no official Docker image for ROS1 Melodic on an ARM64 architecture. 
Therefore, an custom image found [here](https://hub.docker.com/r/tiryoh/ros-melodic-desktop/tags) will be used.

- Pull the image on the RPi
```bash
docker pull --platform=linux/arm64 tiryoh/ros-melodic-desktop:latest
```
- Verify it pulled the correct image
```bash
docker image inspect tiryoh/ros-melodic-desktop:latest --format '{{.Os}}/{{.Architecture}}'
```
It should return **linux/arm64**

## Run the Docker container
### Start command
Run the image with the following command to make it have all the necessary rights, persistency, shared folder etc.
```bash
docker run -it --privileged \
  --network host \
  --env="DISPLAY=$DISPLAY" \
  --env="QT_X11_NO_MITSHM=1" \
  --volume="/tmp/.X11-unix:/tmp/.X11-unix:rw" \
  --volume="$HOME/ros_shared:/ros_shared" \
  --volume="/dev:/dev" \
  --name ros_melodic_container \
  tiryoh/ros-melodic-desktop:latest \
  bash
```

**Note:** The initial setup as well as the later installation of packages for ROS in the docker could have been done using a *docker compose* file. This would be an adjustment to consider for later development. 

### Control a Docker container
These commands are to be executed in a terminal on the host.
- To list all the Docker containers (active and stopped):
```bash
docker ps -a
```
- To list only the active Docker containers:
```bash
docker ps 
```
- To start a persistent container:
```bash
docker start -ai <container_name>
```

**Note:**\
-a -> attach to stdout/stderr\
-i -> interactive shell

- To start a container in the background
```bash
docker start <container_name>
```
- Exit the container. It stops (if it was the last terminal instance in the container) but stays saved.
```bash
exit
```
- To stop a container (gracefully stops the container but is the same as exiting)
```bash
docker stop <container_name>
```
- Link a new terminal to an already running container
```bash
docker exec -it <container_name> bash
```
- Reconnect the current terminal to an already running container
```bash
docker attach <container_name>
```
- Delete a container
```bash
docker rm <container_name>
```

### Docker ROS Melodic Container Command Breakdown

| Command / Option | Description |
|---|---|
| `docker run` | Creates and starts a new container from a Docker image. |
| `-it` | Runs the container in interactive mode with a TTY (`-i` keeps STDIN open, `-t` allocates a terminal). |
| `--privileged` | Grants extended privileges to the container, allowing full access to host devices (commonly required for robotics hardware and drivers). |
| `--network host` | Uses the host’s network stack directly, which simplifies ROS node communication and avoids port forwarding. |
| `--env="DISPLAY=$DISPLAY"` | Passes the host’s X11 display variable so GUI applications inside the container can render on the host. |
| `--env="QT_X11_NO_MITSHM=1"` | Disables MIT shared memory for Qt apps to prevent GUI issues when running Qt applications (e.g., RViz) in Docker. |
| `--volume="/tmp/.X11-unix:/tmp/.X11-unix:rw"` | Mounts the host’s X11 Unix socket into the container to enable GUI forwarding. |
| `--volume="$HOME/ros_shared:/ros_shared"` | Shares a directory between host and container for persistent storage and file exchange. |
| `--volume="/dev:/dev"` | Mounts the host’s `/dev` directory, allowing access to hardware devices such as USB, serial ports, and cameras. |
| `--name ros_melodic_container` | Assigns a readable name to the container for easier management. |
| `tiryoh/ros-melodic-desktop:latest` | The Docker image used: ROS Melodic Desktop with GUI tools, maintained by `tiryoh`. |
| `bash` | Starts an interactive Bash shell inside the container instead of the default command. |

## Arduino ROS library files
- Enter the ROS1 docker container
```bash
docker exec -it <container_name> bash
```
- Install **rosserial_arduino** inside the container
```bash
sudo apt update
sudo apt install ros-noetic-rosserial-arduino ros-noetic-rosserial
```
- Create the **ros_lib** folder
```bash
cd /tmp
rosrun rosserial_arduino make_libraries.py ros_lib
```
There should now be **/tmp/ros_lib/** with files like *ros.h* and folders like *std_msgs/Int16.h* etc.
- Copy **ros_lib** to the host 
```bash
cp -r /tmp/ros_lib /shared_folder/  
```
- Install ros_lib on the Raspberry Pi for Arduino IDE. On the host go to the shared folder and from there move the **ros_lib** folder.
```bash
mv ~/shared_folder/ros_lib ~/Arduino/libraries/ros_lib
```
- The final path must be:
```bash
~/Arduino/libraries/ros_lib/
    ros.h
    std_msgs/
    geometry_msgs/
    ...
```
- Restart the Arduino IDE and compile the code. It should work now.

**Note:** The **ros_lib** folder can be found in this github repository. There is therefore no need to do the previously mentioned steps if necessary.

### Additional configuration
#### .bashrc
- Add to *.bashrc* to auto-source the ROS1 Melodic environment. 
```bash
nano ~/.bashrc
source /opt/ros/melodic/setup.bash
```
- Forwards the display rights for Docker
```bash
xhost +local:root 
```

#### Make bash shell sudo
To make the shell sudo, run:
```bash
sudo su
```

#### Install additional packages
- Install **nano** in the docker
```bash
apt-get install nano
```
- Install **git** in the docker
```bash
apt-get install git
```

## Troubleshooting
### CMake version out-of-date
If the CMake version inside the docker is out-of-date, it can be updated.
1. Update
```bash
sudo apt update
sudo apt install -y build-essential libssl-dev wget tar
```
2. Pick a stable version >= 3.16 (here 3.26.4)
```bash
cd /tmp
wget https://github.com/Kitware/CMake/releases/download/v3.26.4/cmake-3.26.4.tar.gz
tar -zxvf cmake-3.26.4.tar.gz
cd cmake-3.26.4
```
3. Build and install CMake
```bash
./bootstrap
make -j$(nproc)
sudo make install
```
**Note:** -j$(nproc) uses all CPU cores to speed up compilation.
4. Verify the version
```bash
cmake --version
```
It should now show something like cmake version 3.26.4.

## References
- ROS1 Distros and target platforms
https://www.ros.org/reps/rep-0003.html#noetic-ninjemys-may-2020-may-2025

- ROS1 Melodic ARM64 build
https://hub.docker.com/r/tiryoh/ros-melodic-desktop/tags

- ROS Docker Hub
https://hub.docker.com/_/ros/

- Install Docker
https://docs.docker.com/engine/install/ubuntu/

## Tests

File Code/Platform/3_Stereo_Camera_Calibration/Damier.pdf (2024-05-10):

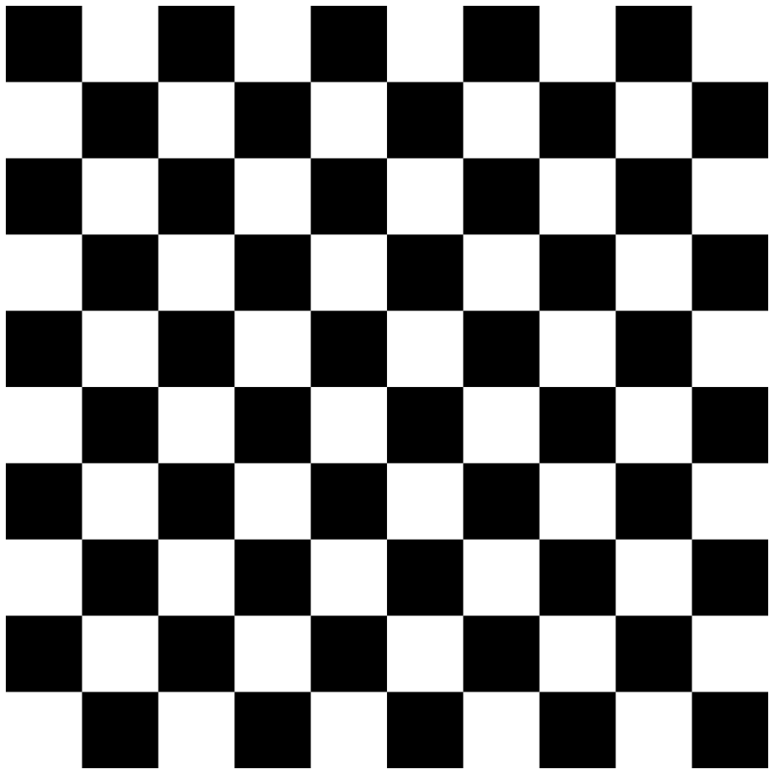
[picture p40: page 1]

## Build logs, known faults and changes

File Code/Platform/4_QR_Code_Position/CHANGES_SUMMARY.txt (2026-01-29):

# Summary of Changes

## Files Modified

### 1. `2_get_camera_parameters.py` (Calibration Script)
**What changed**: Updated to save additional calibration parameters to the `.npz` file.

**New parameters saved**:
- `matrix_right`: Right camera intrinsic matrix
- `matrix_left`: Left camera intrinsic matrix
- `distortion_coef_right`: Right camera distortion coefficients
- `distortion_coef_left`: Left camera distortion coefficients
- `rotation_matrix`: Rotation between cameras
- `translation_vector`: Translation between cameras (contains baseline info)
- `rightRectification`: Right rectification matrix
- `leftRectification`: Left rectification matrix
- `rightProjection`: Right projection matrix
- `leftProjection`: Left projection matrix

**Action needed**: Re-run this script to update your calibration file with the new parameters.

---

### 2. `2_QR_code_position.py` (QR Code Detection Script)
**What changed**: Complete rewrite with new features.

#### New Features:

1. **Automatic Parameter Extraction**
   - Extracts camera matrices from `.npz` file
   - Automatically computes focal length: `f = (K[0,0] + K[1,1]) / 2`
   - Automatically computes principal point: `(cx, cy) = (K[0,2], K[1,2])`
   - Extracts baseline from translation vector: `baseline = abs(T[0][0])`

2. **Continuous Looping Until Match Found**
   - Reads frames continuously after pressing 's'
   - Detects QR codes in both left and right frames every frame
   - **Stops looping** as soon as a matching pair is found
   - Displays 3D position and waits for next 's' press

3. **Improved 3D Calculation**
   - Uses actual calibration parameters instead of approximations
   - Formula: `Z = (f * baseline) / disparity`
   - More accurate X, Y coordinates using principal point

#### New Helper Functions:

- `extract_focal_length(camera_matrix)`: Computes focal length
- `extract_principal_point(camera_matrix)`: Computes principal point
- `triangulate_qr_position()`: Enhanced 3D calculation using real parameters

#### Usage:
```
Press 's' to start QR code detection loop
(program continuously searches for matching QR codes)
When found: displays 3D position and stops
Press 's' again to search for another QR code
Press 'e' to exit
```

---

## How to Use

### Step 1: Re-run Calibration (Important!)
```bash
cd ../Calibration
python 2_get_camera_parameters.py
```
This will save the new parameters to `Saved_parameters/retification_informations.npz`

### Step 2: Run the QR Code Detection
```bash
cd ../QR_Code
python 2_QR_code_position.py
```

### Step 3: Detect QR Codes
- Press 's' to start searching
- Hold a QR code in front of your stereo cameras
- When it appears in both frames, the program will display:
  - QR code data
  - Disparity (pixels)
  - **3D Position** (X, Y, Z in mm relative to left camera)
  - Total distance from camera origin

---

## What If Calibration File Doesn't Have New Parameters?

The script will fall back gracefully:
- It will print "✗ Camera matrices found" (or "✗ Baseline extracted")
- The looping will still work but 3D calculations won't be available
- Re-run the calibration script to add the missing parameters

---

## Coordinate System

**Origin**: Left camera's optical center
- **X-axis**: pointing right (positive = QR code on the right)
- **Y-axis**: pointing down (positive = QR code below center)
- **Z-axis**: pointing forward (positive = QR code in front of camera)

**Example**: Position (100, -50, 500) means:
- 100 mm to the right
- 50 mm above the camera center
- 500 mm away (distance)

---

## Key Improvements Over Previous Version

| Feature | Before | After |
|---|---|---|
| Parameter source | Hard-coded approximations | Extracted from calibration |
| Looping behavior | Only when pressing 's' | Continuous until match found |
| Focal length | `f = 500` (guessed) | Calculated from camera matrix |
| Principal point | `(1280, 360)` (estimated) | Extracted from camera matrix |
| Baseline | `60 mm` (guessed) | From translation vector |
| 3D accuracy | Low (demo only) | High (real calibration data) |

---

## Troubleshooting

**Q: "Warning: Could not load all calibration parameters"**
A: Run `2_get_camera_parameters.py` again to update the calibration file

**Q: No QR codes detected**
A: Ensure the QR code is clearly visible in both camera frames

**Q: 3D position looks wrong**
A: Check that:
1. Calibration was done properly
2. Both cameras are actually a stereo pair
3. Baseline distance is correct
4. QR code is clearly visible in both frames

**Q: Disparity is 0 or negative**
A: QR code might be closer than the focal length or at infinity - try moving QR code in front of camera

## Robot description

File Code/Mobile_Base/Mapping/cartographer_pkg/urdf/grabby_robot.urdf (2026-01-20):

<robot name="grabby">
    <material name="aluminium_grey">
        <color rgba="134.0 133.0 129.0 1.000" />
    </material>
    <material name="black">
        <color rgba="0 0 0 1" />
    </material>
    <material name="green">
        <color rgba="0.0 1.0 0.0 1.0" />
    </material>

    <!-- Base Link -->
    <link name="base_link">
        <visual>
            <geometry>
                <!-- Size: length width height in meters -->
                <box size="0.330 0.280 0.110" />
            </geometry>
            <material name="aluminium_grey"/>
        </visual>
        <collision>
            <geometry>
                <box size="0.330 0.280 0.110" />
            </geometry>
        </collision>
    </link>

    <!-- Base footprint -->
    <link name="base_footprint" />

    <joint name="base_footprint_to_base_link" type="fixed">
        <parent link="base_footprint" />
        <child link="base_link" />
        <origin xyz="0 0 0.025" rpy="0 0 0" />
    </joint>

    <!-- Lidar -->
    <link name="laser">
        <visual>
            <geometry>
                <cylinder length="0.055" radius="0.035" />
            </geometry>
            <material name="black" />
        </visual>
        <collision>
            <geometry>
                <cylinder length="0.055" radius="0.035" />
            </geometry>
        </collision>
    </link>

    <joint name="base_link_to_laser" type="fixed">
        <parent link="base_link" />
        <child link="laser" />
        <!-- <origin xyz="0.0645 0 0.130" rpy="0 0 0" /> -->
        <!-- Use the line below if the LiDAR is pointing backwards (rotates along z of pi) -->
        <origin xyz="0.0645 0 0.130" rpy="0 0 3.1416" />
    </joint>

    <!-- Left Wheel -->
    <link name="left_wheel">
        <visual>
            <geometry>
                <cylinder length="0.025" radius="0.035" /> 
            </geometry>
            <material name="black" />
        </visual>
        <collision>
            <geometry>
                <cylinder length="0.025" radius="0.035" />
            </geometry>
        </collision>
    </link>

    <joint name="base_link_to_left_wheel" type="continuous">
        <parent link="base_link" />
        <child link="left_wheel" />
        <origin xyz="0 -0.078 0" rpy="0 0 0" />
        <axis xyz="0 1 0" />
    </joint>

    <!-- Right Wheel -->
    <link name="right_wheel">
        <visual>
            <geometry>
                <cylinder length="0.025" radius="0.035" />
            </geometry>
            <material name="black" />
        </visual>
        <collision>
            <geometry>
                <cylinder length="0.025" radius="0.035" />
            </geometry>
        </collision>
    </link>

    <joint name="base_link_to_right_wheel" type="continuous">
        <parent link="base_link" />
        <child link="right_wheel" />
        <origin xyz="0 0.078 0" rpy="0 0 0" /> 
        <axis xyz="0 1 0" />
    </joint>

    <!-- IMU -->
    <link name="imu">
        <visual>
            <geometry>
                <box size="0.020 0.020 0.010" /> 
            </geometry>
            <material name="green" />
        </visual>
        <collision>
            <geometry>
                <box size="0.020 0.020 0.010" />
            </geometry>
        </collision>
    </link>

    <joint name="base_link_to_imu" type="fixed">
        <parent link="base_link" />
        <child link="imu" />
        <origin xyz="0.1245 0.0895 0.0" rpy="0 0 0" />  
    </joint>
</robot>

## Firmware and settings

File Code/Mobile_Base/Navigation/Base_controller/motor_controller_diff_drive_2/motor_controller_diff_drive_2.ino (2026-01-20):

/*
 * Project: Grabby the warehouse robot
 * Adapted from: https://automaticaddison.com/how-to-control-a-robots-velocity-remotely-using-ros/
 * Description: ROS node that publishes the accumulated ticks for each wheel
 *              Publish:
 *                  /m1_ticks and /m2_ticks
 *              Subscribe:  
 *                  /cmd_vel 
 */
 
#include <ros.h>
#include <std_msgs/Int16.h>
#include <geometry_msgs/Twist.h>

// Handles startup and shutdown of ROS
ros::NodeHandle nh;

////////////////// Tick Data Publishing Variables and Constants ///////////////

// Encoder output to Arduino Interrupt pin. Tracks the tick count.
#define ENC_IN_LEFT_A 2
#define ENC_IN_RIGHT_A 3

// Other encoder output to Arduino to keep track of wheel direction
// Tracks the direction of rotation.
#define ENC_IN_LEFT_B 8
#define ENC_IN_RIGHT_B 11


// True = Forward; False = Reverse
boolean Direction_left = true;
boolean Direction_right = true;

// Minumum and maximum values for 16-bit integers
// Range of 65,535
const int encoder_minimum = -32768;
const int encoder_maximum = 32767;

// Keep track of the number of wheel ticks
std_msgs::Int16 right_wheel_tick_count;
ros::Publisher rightPub("m1_ticks", &right_wheel_tick_count);

std_msgs::Int16 left_wheel_tick_count;
ros::Publisher leftPub("m2_ticks", &left_wheel_tick_count);

// Time interval for measurements in milliseconds
const int interval = 30;
long previousMillis = 0;
long currentMillis = 0;

////////////////// Motor Controller Variables and Constants ///////////////////

// Motor A connections (Left motor / M1)
const int enA = 5;
const int in1 = 4;
const int in2 = 7;
  
// Motor B connections (Right motor / M2)
const int enB = 6; 
const int in3 = 10;
const int in4 = 9;

// How much the PWM value can change each cycle
const int PWM_INCREMENT = 1;

// Robot specs
const double WHEEL_RADIUS = 0.035; // in meters
const double WHEEL_BASE = 0.18; // in meters
const double WHEEL_CIRCUMFERENCE = 2 * M_PI * WHEEL_RADIUS;
const double GEAR_RATIO = 98.78;
const double MOTOR_SHAFT_TICKS = 12;
const double GEAR_BOX_SHAFT_TICKS = GEAR_RATIO * MOTOR_SHAFT_TICKS;
const double TICKS_PER_REVOLUTION = GEAR_BOX_SHAFT_TICKS;
const double TICKS_PER_METER = TICKS_PER_REVOLUTION / WHEEL_CIRCUMFERENCE; // 5393.45 ticks per meter


// Proportional constant, which was measured by measuring the 
// PWM-Linear Velocity relationship for the robot.
const int K_P = 814.58;

// Y-intercept for the PWM-Linear Velocity relationship for the robot
const int b = -94.74;

// Correction multiplier for drift. Chosen through experimentation.
const int DRIFT_MULTIPLIER = 0;

// Turning PWM output (0 = min, 255 = max for PWM values)
const int PWM_TURN = 80;

// Set maximum and minimum limits for the PWM values
const int PWM_MIN = 80; // about 0.2123 m/s
const int PWM_MAX = 100; // about 0.2363 m/s

// Set linear velocity and PWM variable values for each wheel
double velLeftWheel = 0;
double velRightWheel = 0;
double pwmLeftReq = 0;
double pwmRightReq = 0;

// Record the time that the last velocity command was received
double lastCmdVelReceived = 0;

/////////////////////// Tick Data Publishing Functions ////////////////////////

// Increment the number of ticks
void right_wheel_tick() {
  
  // Read the value for the encoder for the right wheel
  int val = digitalRead(ENC_IN_RIGHT_B);

  if (val == LOW) {
    Direction_right = false; // Reverse
  }
  else {
    Direction_right = true; // Forward
  }
  
  if (Direction_right) {
    
    if (right_wheel_tick_count.data == encoder_maximum) {
      right_wheel_tick_count.data = encoder_minimum;
    }
    else {
      right_wheel_tick_count.data++;  
    }    
  }
  else {
    if (right_wheel_tick_count.data == encoder_minimum) {
      right_wheel_tick_count.data = encoder_maximum;
    }
    else {
      right_wheel_tick_count.data--;  
    }   
  }
}

// Increment the number of ticks
void left_wheel_tick() {
  
  // Read the value for the encoder for the left wheel
  int val = digitalRead(ENC_IN_LEFT_B);

  if (val == LOW) {
    Direction_left = true; // Reverse
  }
  else {
    Direction_left = false; // Forward
  }
  
  if (Direction_left) {
    if (left_wheel_tick_count.data == encoder_maximum) {
      left_wheel_tick_count.data = encoder_minimum;
    }
    else {
      left_wheel_tick_count.data++;  
    }  
  }
  else {
    if (left_wheel_tick_count.data == encoder_minimum) {
      left_wheel_tick_count.data = encoder_maximum;
    }
    else {
      left_wheel_tick_count.data--;  
    }   
  }
}

/////////////////////// Motor Controller Functions ////////////////////////////

// Calculate the left wheel linear velocity in m/s every time a 
// tick count message is rpublished on the /left_ticks topic. 
void calc_vel_left_wheel(){
  
  // Previous timestamp
  static double prevTime = 0;
  
  // Variable gets created and initialized the first time a function is called.
  static int prevLeftCount = 0;

  // Manage rollover and rollunder when we get outside the 16-bit integer range 
  int numOfTicks = (65535 + left_wheel_tick_count.data - prevLeftCount) % 65535;

  // If we have had a big jump, it means the tick count has rolled over.
  if (numOfTicks > 10000) {
        numOfTicks = 0 - (65535 - numOfTicks);
  }

  // Calculate wheel velocity in meters per second
  float RPM2_M1 = (numOfTicks * 60/((millis()-prevTime)*pow(10,-3)))/GEAR_BOX_SHAFT_TICKS; // RPM of gearbox shaft
  velLeftWheel = (RPM2_M1 * WHEEL_CIRCUMFERENCE) / 60.0;

  // Keep track of the previous tick count
  prevLeftCount = left_wheel_tick_count.data;

  // Update the timestamp
  prevTime = (millis()/1000);

}

// Calculate the right wheel linear velocity in m/s every time a 
// tick count message is published on the /right_ticks topic. 
void calc_vel_right_wheel(){
  
  // Previous timestamp
  static double prevTime = 0;
  
  // Variable gets created and initialized the first time a function is called.
  static int prevRightCount = 0;

  // Manage rollover and rollunder when we get outside the 16-bit integer range 
  int numOfTicks = (65535 + right_wheel_tick_count.data - prevRightCount) % 65535;

  if (numOfTicks > 10000) {
        numOfTicks = 0 - (65535 - numOfTicks);
  }

  // Calculate wheel velocity in meters per second
  float RPM2_M2 = (numOfTicks * 60/((millis()-prevTime)*pow(10,-3)))/GEAR_BOX_SHAFT_TICKS; // RPM of gearbox shaft
  velRightWheel = (RPM2_M2 * WHEEL_CIRCUMFERENCE) / 60.0;


  prevRightCount = right_wheel_tick_count.data;
  
  prevTime = (millis()/1000);

}

// Take the velocity command as input and calculate the PWM values.
void calc_pwm_values(const geometry_msgs::Twist& cmdVel) {
  
  // Record timestamp of last velocity command received
  lastCmdVelReceived = (millis()/1000);
  
  // Calculate the PWM value given the desired velocity 
  pwmLeftReq = -(K_P * cmdVel.linear.x + b);
  pwmRightReq = -(K_P * cmdVel.linear.x + b);

  //if (abs(cmdVel.linear.x) < 0.2123){
    //pwmLeftReq = 0;
    //pwmRightReq = 0;
  //}

  if (abs(cmdVel.linear.x) < 0.10){
    pwmLeftReq = 0;
    pwmRightReq = 0;
  }

  // Check if we need to turn 
  if (cmdVel.angular.z != 0.0) {

    // Turn left
    if (cmdVel.angular.z > 0.0) {
      pwmLeftReq = -PWM_TURN;
      pwmRightReq = PWM_TURN;
    }
    // Turn right    
    else {
      pwmLeftReq = PWM_TURN;
      pwmRightReq = -PWM_TURN;
    }
  }
  // Go straight
  else {
    // Correction factor for motor imbalance
    const double CORRECTION_FACTOR = 5; // Tune this experimentally

    // Apply correction to only one motor (e.g., the right one)
    pwmLeftReq +=  CORRECTION_FACTOR;
  }

  // Handle low PWM values
  if (abs(pwmLeftReq) < PWM_MIN) {
    pwmLeftReq = 0;
  }
  if (abs(pwmRightReq) < PWM_MIN) {
    pwmRightReq = 0;  
  }  
}

void set_pwm_values() {

  // These variables will hold our desired PWM values
  static int pwmLeftOut = 0;
  static int pwmRightOut = 0;

  // If the required PWM is of opposite sign as the output PWM, we want to
  // stop the car before switching direction
  static bool stopped = false;
  if ((pwmLeftReq * velLeftWheel < 0 && pwmLeftOut != 0) ||
      (pwmRightReq * velRightWheel < 0 && pwmRightOut != 0)) {
    pwmLeftReq = 0;
    pwmRightReq = 0;
  }

  // Set the direction of the motors
  if (pwmLeftReq > 0) { // Left wheel forward
    digitalWrite(in1, HIGH);
    digitalWrite(in2, LOW);
  }
  else if (pwmLeftReq < 0) { // Left wheel reverse
    digitalWrite(in1, LOW);
    digitalWrite(in2, HIGH);
  }
  else if (pwmLeftReq == 0 && pwmLeftOut == 0 ) { // Left wheel stop
    digitalWrite(in1, LOW);
    digitalWrite(in2, LOW);
  }
  else { // Left wheel stop
    digitalWrite(in1, LOW);
    digitalWrite(in2, LOW); 
  }

  if (pwmRightReq > 0) { // Right wheel forward
    digitalWrite(in3, HIGH);
    digitalWrite(in4, LOW);
  }
  else if(pwmRightReq < 0) { // Right wheel reverse
    digitalWrite(in3, LOW);
    digitalWrite(in4, HIGH);
  }
  else if (pwmRightReq == 0 && pwmRightOut == 0) { // Right wheel stop
    digitalWrite(in3, LOW);
    digitalWrite(in4, LOW);
  }
  else { // Right wheel stop
    digitalWrite(in3, LOW);
    digitalWrite(in4, LOW); 
  }

  // Increase the required PWM if the robot is not moving
  if (pwmLeftReq != 0 && velLeftWheel == 0) {
    pwmLeftReq *= 1.5;
  }
  if (pwmRightReq != 0 && velRightWheel == 0) {
    pwmRightReq *= 1.5;
  }

  // Calculate the output PWM value by making slow changes to the current value
  if (abs(pwmLeftReq) > pwmLeftOut) {
    pwmLeftOut += PWM_INCREMENT;
  }
  else if (abs(pwmLeftReq) < pwmLeftOut) {
    pwmLeftOut -= PWM_INCREMENT;
  }
  else{}
  
  if (abs(pwmRightReq) > pwmRightOut) {
    pwmRightOut += PWM_INCREMENT;
  }
  else if(abs(pwmRightReq) < pwmRightOut) {
    pwmRightOut -= PWM_INCREMENT;
  }
  else{}

  // Conditional operator to limit PWM output at the maximum 
  pwmLeftOut = (pwmLeftOut > PWM_MAX) ? PWM_MAX : pwmLeftOut;
  pwmRightOut = (pwmRightOut > PWM_MAX) ? PWM_MAX : pwmRightOut;

  // PWM output cannot be less than 0
  pwmLeftOut = (pwmLeftOut < 0) ? 0 : pwmLeftOut;
  pwmRightOut = (pwmRightOut < 0) ? 0 : pwmRightOut;

  // Set the PWM value on the pins
  analogWrite(enA, pwmLeftOut); 
  analogWrite(enB, pwmRightOut); 

}

// Set up ROS subscriber to the velocity command
ros::Subscriber<geometry_msgs::Twist> subCmdVel("cmd_vel", &calc_pwm_values );

void setup() {

  // Set pin states of the encoder
  pinMode(ENC_IN_LEFT_A , INPUT_PULLUP);
  pinMode(ENC_IN_LEFT_B , INPUT);
  pinMode(ENC_IN_RIGHT_A , INPUT_PULLUP);
  pinMode(ENC_IN_RIGHT_B , INPUT);

  // Every time the pin goes high, this is a tick
  attachInterrupt(digitalPinToInterrupt(ENC_IN_LEFT_A), left_wheel_tick, RISING);
  attachInterrupt(digitalPinToInterrupt(ENC_IN_RIGHT_A), right_wheel_tick, RISING);
  
  // Motor control pins are outputs
  pinMode(enA, OUTPUT);
  pinMode(enB, OUTPUT);
  pinMode(in1, OUTPUT);
  pinMode(in2, OUTPUT);
  pinMode(in3, OUTPUT);
  pinMode(in4, OUTPUT);
  
  // Turn off motors - Initial state
  digitalWrite(in1, LOW);
  digitalWrite(in2, LOW);
  digitalWrite(in3, LOW);
  digitalWrite(in4, LOW);
  
  // Set the motor speed
  analogWrite(enA, 0); 
  analogWrite(enB, 0);

  // ROS Setup
  nh.getHardware()->setBaud(115200);
  nh.initNode();
  nh.advertise(rightPub);
  nh.advertise(leftPub);
  nh.subscribe(subCmdVel);
}

void loop() {
  
  nh.spinOnce();
  
  // Record the time
  currentMillis = millis();

  // If the time interval has passed, publish the number of ticks,
  // and calculate the velocities.
  if (currentMillis - previousMillis > interval) {
    
    previousMillis = currentMillis;

    // Publish tick counts to topics
    leftPub.publish( &left_wheel_tick_count );
    rightPub.publish( &right_wheel_tick_count );

    // Calculate the velocity of the right and left wheels
    calc_vel_right_wheel();
    calc_vel_left_wheel();
    
  }
  
  // Stop the car if there are no cmd_vel messages
  if((millis()/1000) - lastCmdVelReceived > 1) {
    pwmLeftReq = 0;
    pwmRightReq = 0;
  }

  set_pwm_values();
}

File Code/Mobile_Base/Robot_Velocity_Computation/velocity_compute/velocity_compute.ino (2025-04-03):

/* Project: Grabby the Warehouse robot
 * Description: Displays the calculated values through a serial connection over bluetooth (COM8) in PuTTy
 * Chose COM8 at 9600 baudrate
 * Allows to compute the velocity of the robot
 * Julius Ortstadt
 * 03.03.2025
*/

#include <SoftwareSerial.h>
#include <math.h>
#define RX 24 // = TX pin on module
#define TX 23 // = RX pin on module via a voltage divider

SoftwareSerial BlueT(RX,TX);

//---------------// Motor Properties //---------------//
// Motor gear ratio
float gear_ratio = 98.78;

// Motor shaft ticks per revolution for channel A rising:
float m_shaft_ticks = 12;
float g_shaft_ticks = m_shaft_ticks * gear_ratio;

//---------------// Encoder Setup //---------------//
// Define the pins for the motor encoder
// WARNING: Pins need to be pins that can be interrupted (see list for Arduino)
#define enc_M1_A 2 // Yellow for encoder A
#define enc_M1_B 3 // White for encoder B

#define enc_M2_A 18 // Yellow for encoder A
#define enc_M2_B 19 // White for encoder B

//---------------// Motor Setup //---------------//
// Motor 1 control pins
const int IN1=39; // Pin for control signal to change motor behaviour
const int IN2=40; // Pin for control signal to change motor behaviour
const int ENA=45; // Pin for PWM

// Motor 2 control pins
// IN3 & IN4 need to be inverted compared to the actual cabling because the motors are mounted on opposit sides
const int IN3=42; // Pin for control signal to change motor behaviour
const int IN4=41; // Pin for control signal to change motor behaviour
const int ENB=44; // Pin for PWM

//---------------// Variable Declaration //---------------//
// Tick counter
volatile long M1_tick_count = 0;
volatile long M2_tick_count = 0;

// Distance 
float M1_distance = 0;
float M2_distance = 0;

// Motor speed
int speed = 200;

// Measurement interval & time keepers
int interval = 5000; // ms
long previousMillis = 0;
long currentMillis = 0;

// Wheel
const float wheel_diameter = 70 * pow(10,-3); // m
const float wheel_circumference = M_PI * wheel_diameter; // m

// Measurement counter
int measurement = 1;

bool test;

//---------------// Proportional Controller //---------------//
// P controller gain
float Kp = 2.0;

// Target RPM for both motors (Max gearbox RPM is 100)
int target_RPM = 80;



void setup() {
  // put your setup code here, to run once:
  Serial.begin(9600);
  Serial.println("Enter AT commands: ");

  // HC-06 Bluetooth module
  BlueT.begin(9600);

  // Set the pinMode of the encoders
  pinMode(enc_M1_A, INPUT_PULLUP);
  pinMode(enc_M2_A, INPUT_PULLUP);

  // When the pin goes HIGH we interrupt (therefore the volatile long)
  attachInterrupt(digitalPinToInterrupt(enc_M1_A), M1_tick, RISING);
  attachInterrupt(digitalPinToInterrupt(enc_M2_A), M2_tick, RISING);

  // Setup for motor 1 pins
  pinMode(IN1, OUTPUT);
  pinMode(IN2, OUTPUT);
  pinMode(ENA, OUTPUT);

  // Setup for motor 2 pins
  pinMode(IN3, OUTPUT);
  pinMode(IN4, OUTPUT);
  pinMode(ENB, OUTPUT);

  // Stop the motor
  stop();

  // Start millis()
  previousMillis = millis();

  // Set test status
  test = true;
}

void loop() {
  // put your main code here, to run repeatedly:
  currentMillis = millis();

  if (test){
    // Read encoder values and compute RPM
    float RPM2_M1 = (M1_tick_count * 60/(interval*pow(10,-3)))/g_shaft_ticks; // RPM of gearbox shaft
    float RPM2_M2 = (M2_tick_count * 60/(interval*pow(10,-3)))/g_shaft_ticks; // RPM of gearbox shaft

    // Compute error (difference in speed)
    float error = RPM2_M1 - RPM2_M2;

    // Compute correction using P controller
    int correction = Kp * error;

    // Adjust motor speeds
    int speed_M1 = constrain(speed - correction, 0, 255);
    int speed_M2 = constrain(speed + correction, 0, 255);

    // Drive the motors forward
    forward(speed_M1, speed_M2);

    // Calculate and send the results via Bluetooth
    if (currentMillis - previousMillis > interval){
      previousMillis = currentMillis;
      stop();
      // Compute and print the measurements
      print_BT();
    
      measurement++;

      // Reset of the variables
      // Tick counter
      M1_tick_count = 0;
      M2_tick_count = 0;

      test = false;
    }
  }

  else {
    stop();
  }
  

}


void M1_tick(){
  M1_tick_count++;
}

void M2_tick(){
  M2_tick_count++;
}

void stop(){ // Stop
  // Stop motor 1
  digitalWrite(IN1, LOW);
  digitalWrite(IN2, LOW);

  // Stop motor 2
  digitalWrite(IN3, LOW);
  digitalWrite(IN4, LOW);
}

void forward(int speed_M1, int speed_M2){ // Moves forward
  // Motor 1 forward 
  digitalWrite(IN1, LOW);
  digitalWrite(IN2, HIGH);
  analogWrite(ENA, speed_M1);

  // Motor 2 forward
  digitalWrite(IN3, LOW);
  digitalWrite(IN4, HIGH);
  analogWrite(ENB, speed_M2);
}

void print_BT(){
  BlueT.println(" ");
  // All the data related to motor 1
  BlueT.println("-----> Motor M1 Data <----- Measurement: " + String(measurement));
  BlueT.println("M1 tick count: " + String(M1_tick_count));
  float RPM1_M1 = (M1_tick_count * 60/(interval*pow(10,-3)))/m_shaft_ticks; // RPM of motor shaft
  float RPM2_M1 = (M1_tick_count * 60/(interval*pow(10,-3)))/g_shaft_ticks; // RPM of gearbox shaft
  BlueT.println("RPM Motor shaft value at " + String(speed) + " PWM: " + String(RPM1_M1));
  BlueT.println("RPM Gearbox shaft value at " + String(speed) + " PWM: " + String(RPM2_M1));
  M1_distance += (RPM2_M1 / 60) * wheel_circumference * (interval * pow(10,-3));
  BlueT.println("Distance travelled in m: " + String(M1_distance));
  float M1_velocity = (RPM2_M1 * wheel_circumference) / 60.0;
  BlueT.println("Velocity in m/s: " + String(M1_velocity));

  BlueT.println(" ");
  BlueT.println(" ");

  // All the data related to motor 2
  BlueT.println("-----> Motor M2 Data <----- Measurement: " + String(measurement));
  BlueT.println("M2 tick count: " + String(M2_tick_count));
  float RPM1_M2 = (M2_tick_count * 60/(interval*pow(10,-3)))/m_shaft_ticks; // RPM of motor shaft
  float RPM2_M2 = (M2_tick_count * 60/(interval*pow(10,-3)))/g_shaft_ticks; // RPM of gearbox shaft
  BlueT.println("RPM Motor shaft value at " + String(speed) + " PWM: " + String(RPM1_M2));
  BlueT.println("RPM Gearbox shaft value at " + String(speed) + " PWM: " + String(RPM2_M2));
  M2_distance += (RPM2_M2 / 60) * wheel_circumference * (interval * pow(10,-3));
  BlueT.println("Distance travelled in m: " + String(M2_distance));
  float M2_velocity = (RPM2_M2 * wheel_circumference) / 60.0;
  BlueT.println("Velocity in m/s: " + String(M2_velocity));

  BlueT.println(" ");

  BlueT.println("-------------------------------------------");
}

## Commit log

2024-02-14 Adding repertories
    adding repertories for 3D and 2D model files andfor test code this will be serated in two repertories one for Julius and one for Jeremy.
    The repertory GrabbyCode will have no subdivision because it will contain the final code for the robot.
    [28BYJ_fixation.3mf, Belt_fixation.3mf, LATTICE.dxf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]
2024-03-15 3D files and arduino test code
    OLED and TOF sensor test code
    [CommandeGrabby2.xlsx, FrameBackLeft.3mf, Frame_v46.f3d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]
2024-03-20 Reorganisation files
    [28BYJ_fixation.3mf, Belt_fixation.3mf, FrameBackLeft.3mf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]
2024-03-30 Seesion report 14 and solid works files
    [frame_back_right.SLDPRT, suction_cup_holder.SLDPRT]
2024-04-09 Session report 16 and other component test
    Code bar reader
    OLED screen
    TOF sensor
    Session report 16
2024-04-18 Session report 17
    I2C welding problem, QR code reader, Stereo camera
2024-05-10 Camera
    intrinsic and extrinsic Stereo camera paramters, disparity map, BM tuner
2025-04-03 Updated Repo for Robo4
    Added everything regarding mobile base and rearranged some elements.
    Still misses the ROS Mapping and Navigation parts as they are still under development.
    [Backplate.3mf, Case.3mf, H_Adapter.3mf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]
2025-04-04 Added Mapping folder to repo
    [grabby_robot.urdf]
2025-04-11 Added documents
    - Project presentation (Robo4)
    - Main component and material list
    [Order_2.xlsx]
2026-01-20 Added files (CAD, code, documentation) for mobile base ROBO5 year
    [BNO055_Case.3mf, Back_bottom_bottom_panel.dxf, Back_bottom_top_panel.dxf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]
2026-01-20 Modified main READM.me at repo root. Added electrical wiring schematics for mobile base. Organized some things.
    [Grabby_pwr.fzz]
2026-01-21 Moved code for main power system
2026-01-29 kalman filter, stereo camera calibration and Qr code detection
